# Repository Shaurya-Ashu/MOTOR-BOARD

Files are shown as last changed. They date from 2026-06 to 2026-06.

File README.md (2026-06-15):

# MOTOR-BOARD
It's a DEV Board specially developed for controlling motors.
We can use this dev board to make anything from a moving car a self balancing robot or even a CNC mill machine.
It's like a all in one mobility powerhouse.

# Why 
 becaue i always wamted one 
 a dev borad which i can directly use to drive a car or make a robotic arm possibilities are endless.
 And also creating a dev board is a fun project.

# BOM
 We have a normal [BOM](BOM/Untitled%20spreadsheet%20-%20BOM.csv)
 & a interactive one https://shaurya-ashu.github.io/MOTOR-BOARD/index.html

# Zine
 Frame 1-2

 It's my first time creating this
 
# Info
It is a dev board based on ESP32-S3-WROOM-1 (My FAV.) mcu, specially designed for multiple types of motors from brushed DC motors, Servo Motors stepper motors etc.
Screenshot 2026-06-09 at 7 26 10 PM

I have used a USB-C port for programming and powering Electronics and the dedicated 3S input for powering the motors.
Screenshot 2026-06-09 at 7 27 20 PM

I have used a INPUT VOLTAGE MULTIPLEXER for selecting between the USB-C power source and battery power source to power the electronics , its is set default to USB power and if USB power is unavailable, then it uses the battery power source.
I get to know about this in a Instagram reel where someone was building custom ESC.
Screenshot 2026-06-09 at 7 28 06 PM

We have to dedicated LDO to convert USB power source and battery power source to 3.3v .
It's a AMS1117-3.3 rated output at 3.3v @1000mah 
Screenshot 2026-06-09 at 7 28 37 PM

It has three peripheral interfaces which you are UART,I2C & SPI .
Which we can use to connect different sensors displays and other devices and also setup a serial communication between two MCU.

Screenshot 2026-06-09 at 7 29 10 PM

Now lets begin with the main part of the schematics the motor drivers and the selector .
So i have used two 3-Way Switches for selecting between diff motors to drive .
we have 2x-TB6612FNG to drive 4x-DC brushless motor
Screenshot 2026-06-09 at 7 29 52 PM

4x-Breakout_A4988 where we can insert A4988 Module to run 4x-Stepper motors.
Screenshot 2026-06-09 at 7 30 38 PM

also to power the servo i have used 2x-ST1S41PHR buck converter so that each servo can get up-to 6v @1A .
Screenshot 2026-06-09 at 7 31 12 PM

Now the the switching part so i have divide it like this in the diagram below :-
DIAGRAM-SELECTOR
Here the vcc enables the drivers for dc-motors & stepper motor and the buck converter for servo's.
The control pins are connected to same pins for for dc-motors , stepper motor & servo .

# Config

 So, all the three thing the dc motor driver , servo & stepper are connected to same GPIO's 
 like this 
 | Net | ESP32-S3 GPIO | Servo Output | A4988 Stepper Driver | TB6612FNG DC Driver |
|:---:|:-------------:|:-------------:|:--------------------:|:-------------------:|
| A1  | GPIO1  | Servo A1 | Stepper 1 ENABLE | M1 PWMA |
| A2  | GPIO2  | Servo A2 | Stepper 1 STEP   | M2 PWMB |
| A3  | GPIO15 | Servo A3 | Stepper 1 DIR    | M1 AIN1 |
| A4  | GPIO4  | Servo A4 | Stepper 2 ENABLE | M1 AIN2 |
| A5  | GPIO5  | Servo A5 | Stepper 2 STEP   | M2 BIN1 |
| A6  | GPIO6  | Servo A6 | Stepper 2 DIR    | M2 BIN2 |
| A7  | GPIO7  | Servo A7 | Stepper 3 ENABLE | M3 PWMA |
| A8  | GPIO22 | Servo A8 | Stepper 3 STEP   | M4 PWMB |
| A9  | GPIO8  | — | Stepper 3 DIR    | M3 AIN1 |
| A10 | GPIO9  | — | Stepper 4 ENABLE | M3 AIN2 |
| A11 | GPIO10 | — | Stepper 4 STEP   | M4 BIN1 |
| A12 | GPIO11 | — | Stepper 4 DIR    | M4 BIN2 |

# PCB

So it's a 4 layer PCB
Confi as:
# Top layer - Signal
Screenshot 2026-06-10 at 1 47 24 PM

# 1 inner layer - GND
Screenshot 2026-06-10 at 1 47 37 PM

# 2 inner layer - Power
Screenshot 2026-06-10 at 1 47 53 PM

# Bottom layer - Signal
Screenshot 2026-06-10 at 1 48 08 PM

the GND layer is divide into two parts then normal electronics and the power/driver electronics and is connected by a single trace .
Screenshot 2026-06-10 at 1 47 37 PM

# Img 

motor-board-img
Screenshot 2026-06-10 at 11 27 02 AM
Screenshot 2026-06-10 at 12 37 49 PM

# Build

Just Order the production gerber file from any pcb manufacturer
And other all the components of DigiKey as listed in the bom

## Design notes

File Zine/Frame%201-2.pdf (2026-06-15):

# MOTOR BOARD

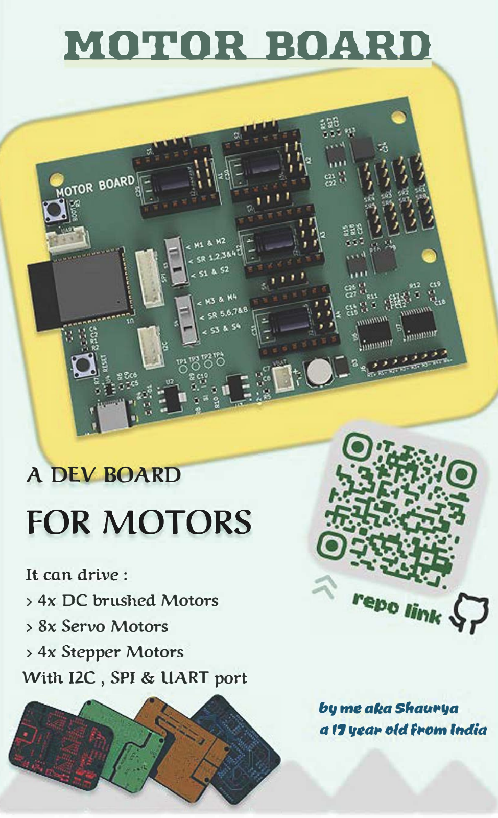
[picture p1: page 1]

A DEV BOARD

## FOR MOTORS

It can drive :
> 4x DC brushed Motors
> 8x Servo Motors
> 4x Stepper Motors
With 12C , SPI & UART port

b!f me alta S"ac.,.11a
a 1711ea,. o(d ftoom India

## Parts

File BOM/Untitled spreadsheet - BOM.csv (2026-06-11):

BILL OF MATERIALS
Item No. | Reference(s) | Description | Footprint / Package | Qty | Unit Price (USD) | Total Value (USD) | Purchase Link
1 | A1, A2, A3, A4 | Pololu A4988 Stepper Motor Driver Breakout (Black Ed.) | Module 15.2×20.3 mm (16-pin) | 4 | $5.95 | $23.80 | https://www.pololu.com/product/2128
2 | C1, C5, C6, C7, C8 | Capacitor, 22 µF, SMD 0603 | C_0603_1608Metric HandSolder | 5 | $0.12 | $0.60 | https://www.digikey.com/en/products/filter/ceramic-capacitors/60
3 | C2, C9, C10, C11, C23, C25 | Capacitor, 1 µF, SMD 0603 | C_0603_1608Metric HandSolder | 6 | $0.10 | $0.60 | https://www.digikey.com/en/products/filter/ceramic-capacitors/60
4 | C3, C4, C12, C14, C17, C18 | Capacitor, 100 nF (0.1 µF), SMD 0603 | C_0603_1608Metric HandSolder | 6 | $0.08 | $0.48 | https://www.digikey.com/en/products/filter/ceramic-capacitors/60
5 | C13, C15, C16, C19, C21, C22, C26, C27 | Capacitor, 10 µF, SMD 0603 | C_0603_1608Metric HandSolder | 8 | $0.15 | $1.20 | https://www.digikey.com/en/products/filter/ceramic-capacitors/60
6 | C20 | Capacitor, 10 µF, Electrolytic THT | C_Elec 6.3×5.4 mm | 1 | $0.20 | $0.20 | https://www.digikey.com/en/products/filter/aluminum-electrolytic-capacitors/58
7 | C24, C28 | Capacitor, 47 µF, SMD 0603 | C_0603_1608Metric HandSolder | 2 | $0.22 | $0.44 | https://www.digikey.com/en/products/filter/ceramic-capacitors/60
8 | C29, C30, C31, C32 | Capacitor, 100 µF, Electrolytic THT | C_Rect L7.2×W3.5 mm P5.00 mm | 4 | $0.25 | $1.00 | https://www.digikey.com/en/products/filter/aluminum-electrolytic-capacitors/58
9 | D1, D2 | LED, General Purpose, SMD 0201 (0603 pads) | LED_0201_0603Metric HandSolder | 2 | $0.10 | $0.20 | https://www.digikey.com/en/products/filter/leds-through-hole/93
10 | D3 | SMBJ30CA-13-F — 30 V Bidirectional TVS Diode | SMB (DO-214AA) / DIOM4336 | 1 | $0.55 | $0.55 | https://www.digikey.com/en/products/detail/diodes-incorporated/SMBJ30CA-13-F/814937
11 | IC1, IC2 | ST1S41PHR — 3 A Step-Down Switching Regulator | SOIC-9 (SOIC127P600X170-9N) | 2 | $1.85 | $3.70 | https://www.mouser.com/ProductDetail/STMicroelectronics/ST1S41PHR?qs=GlLcxsc1hfH42vbX3xy6fg%3D%3D
12 | J1 | 2340901-1 — TE Connectivity Connector | TE_2340901-1 | 1 | $1.20 | $1.20 | https://www.digikey.com/en/products/detail/te-connectivity-amp-connectors/2340901-1/
13 | J2 | JST PH 2-Pin Vertical Connector (2.00 mm pitch) | JST_PH B2B-PH-K 1×02 P2.00 mm | 1 | $0.35 | $0.35 | https://www.digikey.com/en/products/detail/jst-sales-america-inc/B2B-PH-K-S-LF-SN/926626
14 | J3, J5 | JST PH 4-Pin Vertical Connector (2.00 mm pitch) | JST_PH B4B-PH-K 1×04 P2.00 mm | 2 | $0.45 | $0.90 | https://www.digikey.com/en/products/detail/jst-sales-america-inc/B4B-PH-K-S-LF-SN/926628
15 | J4 | JST PH 6-Pin Vertical Connector (2.00 mm pitch) | JST_PH B6B-PH-K 1×06 P2.00 mm | 1 | $0.55 | $0.55 | https://www.digikey.com/en/products/detail/jst-sales-america-inc/B6B-PH-K-S-LF-SN/926630
16 | J6 | 1×8 Female Pin Header 2.54 mm pitch | PinHeader_1×08 P2.54 mm Vertical | 1 | $0.30 | $0.30 | https://www.digikey.com/en/products/filter/rectangular-connectors-headers-receptacles/315
17 | J7–J14 (8 pcs) | 1×3 Male Pin Header 2.54 mm pitch | PinHeader_1×03 P2.54 mm Vertical | 8 | $0.10 | $0.80 | https://www.digikey.com/en/products/filter/rectangular-connectors-headers-male-pins/314
18 | J15, J16, J17, J18 | 1×4 Male Pin Header 2.54 mm pitch | PinHeader_1×04 P2.54 mm Vertical | 4 | $0.12 | $0.48 | https://www.digikey.com/en/products/filter/rectangular-connectors-headers-male-pins/314
19 | J19–J30 (12 pcs) | 1×2 Male Pin Header 2.54 mm pitch | PinHeader_1×02 P2.54 mm Vertical | 12 | $0.08 | $0.96 | https://www.digikey.com/en/products/filter/rectangular-connectors-headers-male-pins/314
20 | L1, L2 | XAL5030-332MEC — 3.3 µH 4.7 A Shielded Power Inductor | XAL5030 (5×5×3 mm) | 2 | $1.98 | $3.96 | https://www.mouser.com/ProductDetail/Coilcraft/XAL5030-332MEC?qs=zCSbvcPd3pYGD73YPsvPxA%3D%3D
21 | R1, R13, R16 | Resistor, 10 kΩ, SMD 0603 | R_0603_1608Metric HandSolder | 3 | $0.05 | $0.15 | https://www.digikey.com/en/products/filter/chip-resistor-surface-mount/52
22 | R2, R3 | Resistor, 0 Ω (Jumper), SMD 0603 | R_0603_1608Metric HandSolder | 2 | $0.05 | $0.10 | https://www.digikey.com/en/products/filter/chip-resistor-surface-mount/52
23 | R4, R5, R10, R11, R12, R17, R18 | Resistor, 1 kΩ, SMD 0603 | R_0603_1608Metric HandSolder | 7 | $0.05 | $0.35 | https://www.digikey.com/en/products/filter/chip-resistor-surface-mount/52
24 | R6, R7 | Resistor, 5.1 kΩ, SMD 0603 | R_0603_1608Metric HandSolder | 2 | $0.05 | $0.10 | https://www.digikey.com/en/products/filter/chip-resistor-surface-mount/52
25 | R8, R9 | Resistor, 47 Ω, SMD 0603 | R_0603_1608Metric HandSolder | 2 | $0.05 | $0.10 | https://www.digikey.com/en/products/filter/chip-resistor-surface-mount/52
26 | R14, R15 | Resistor, 68 kΩ, SMD 0603 | R_0603_1608Metric HandSolder | 2 | $0.05 | $0.10 | https://www.digikey.com/en/products/filter/chip-resistor-surface-mount/52
27 | S1, S2 | Tactile Push Button (BUTT-2) | SW_BUTT-2 | 2 | $0.25 | $0.50 | https://www.digikey.com/en/products/filter/tactile-switches/197
28 | S3, S4 | OS103011MS8QP1 — SPDT Slide Switch | OS103011MS8QP1 | 2 | $0.45 | $0.90 | https://www.digikey.com/en/products/detail/c-k/OS103011MS8QP1/1981429
29 | TP1 | Test Point — VBUS 3.3 V | TestPoint_Pad D1.5 mm | 1 | $0.05 | $0.05 | https://www.digikey.com/en/products/filter/test-points/639
30 | TP2 | Test Point — VBAT 3.3 V | TestPoint_Pad D1.5 mm | 1 | $0.05 | $0.05 | https://www.digikey.com/en/products/filter/test-points/639
31 | TP3, TP4 | Test Point — General Purpose | TestPoint_Pad D1.5 mm | 2 | $0.05 | $0.10 | https://www.digikey.com/en/products/filter/test-points/639
32 | U1 | ESP32-S3-WROOM-1 — WiFi/BT5 Module (PCB ant.) | RF_Module:ESP32-S3-WROOM-1 | 1 | $3.50 | $3.50 | https://www.digikey.com/en/products/detail/espressif-systems/ESP32-S3-WROOM-1-N4/16162639
33 | U2, U3 | AMS1117-3.3 — 1 A LDO Voltage Regulator 3.3 V | SOT-223-3 TabPin2 | 2 | $0.30 | $0.60 | https://www.digikey.com/en/products/detail/umw/AMS1117-3.3/17084460
34 | U4 | USBLC6-2SC6 — USB ESD Protection, SOT-23-6 | SOT-23-6 | 1 | $0.54 | $0.54 | https://www.digikey.com/en/products/detail/stmicroelectronics/USBLC6-2SC6/1787534
35 | U5 | TPS2116DRLR — Power Mux / Priority Switch | SOT-FL50P160×60-8N (VSON-8) | 1 | $0.80 | $0.80 | https://www.digikey.com/en/products/detail/texas-instruments/TPS2116DRLR/15205127
36 | U6, U7 | TB6612FNG — Dual H-Bridge DC Motor Driver | SSOP-24 5.3×8.2 mm P0.65 mm | 2 | $2.72 | $5.44 | https://www.digikey.com/en/products/detail/toshiba-semiconductor-and-storage/TB6612FNGC8EL/1730134
37 | PCB | PCB | -- | 5 | $1.40 | $7.00 | NA
GRAND TOTAL (USD) |  |  |  |  |  | $62.65

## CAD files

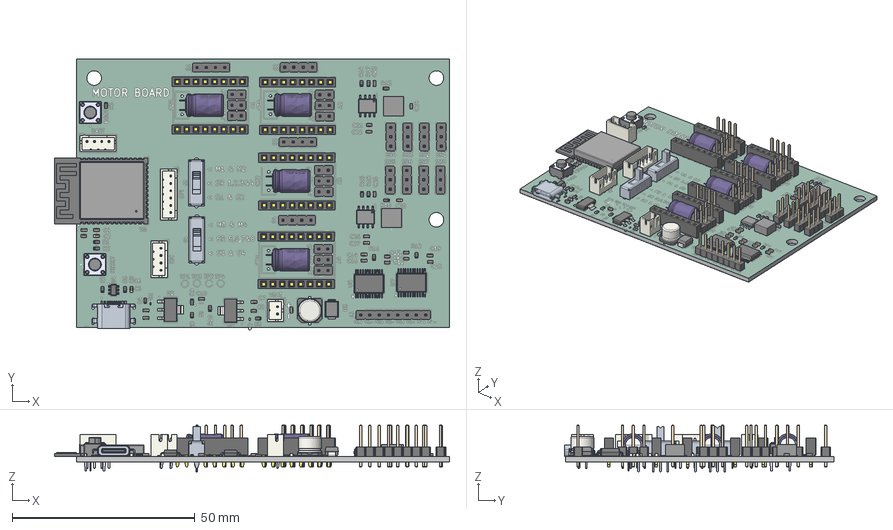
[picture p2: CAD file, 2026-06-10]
PCB/3D Model/moto board.step
107.9 x 74.1 x 12.8 mm
Pins x 2
8er Pin Header Female x 8
R_0603_1608Metric x 18
C_0603_1608Metric x 27
PinHeader_1x02_P2.54mm_Vertical x 12
BUTT-2 x 2
PinHeader_1x03_P2.54mm_Vertical x 8
User Library-Cap-EL(12_5x20-5)T x 4
ESP32-S3-WROOM-1
OS103011MS8QP1 x 2
PinsArrayLR x 2
ThermalPad x 2
SOT-223 x 2
JST_PH_B4B-PH-K_1x04_P2.00mm_Vertical x 2
PinHeader_1x04_P2.54mm_Vertical x 4
SOT-23-6
PinHeader_1x08_P2.54mm_Vertical
JST_PH_B6B-PH-K_1x06_P2.00mm_Vertical
C_Elec_6.3x5.4
LED_0201_0603Metric x 2
SSOP-24_5.3x8.2mm_P0.65mm x 2
JST_PH_B2B-PH-K_1x02_P2.00mm_Vertical
SMBJ30CA-13-F
moto board_silkscreen x 2
moto board_soldermask x 2
moto board_PCB

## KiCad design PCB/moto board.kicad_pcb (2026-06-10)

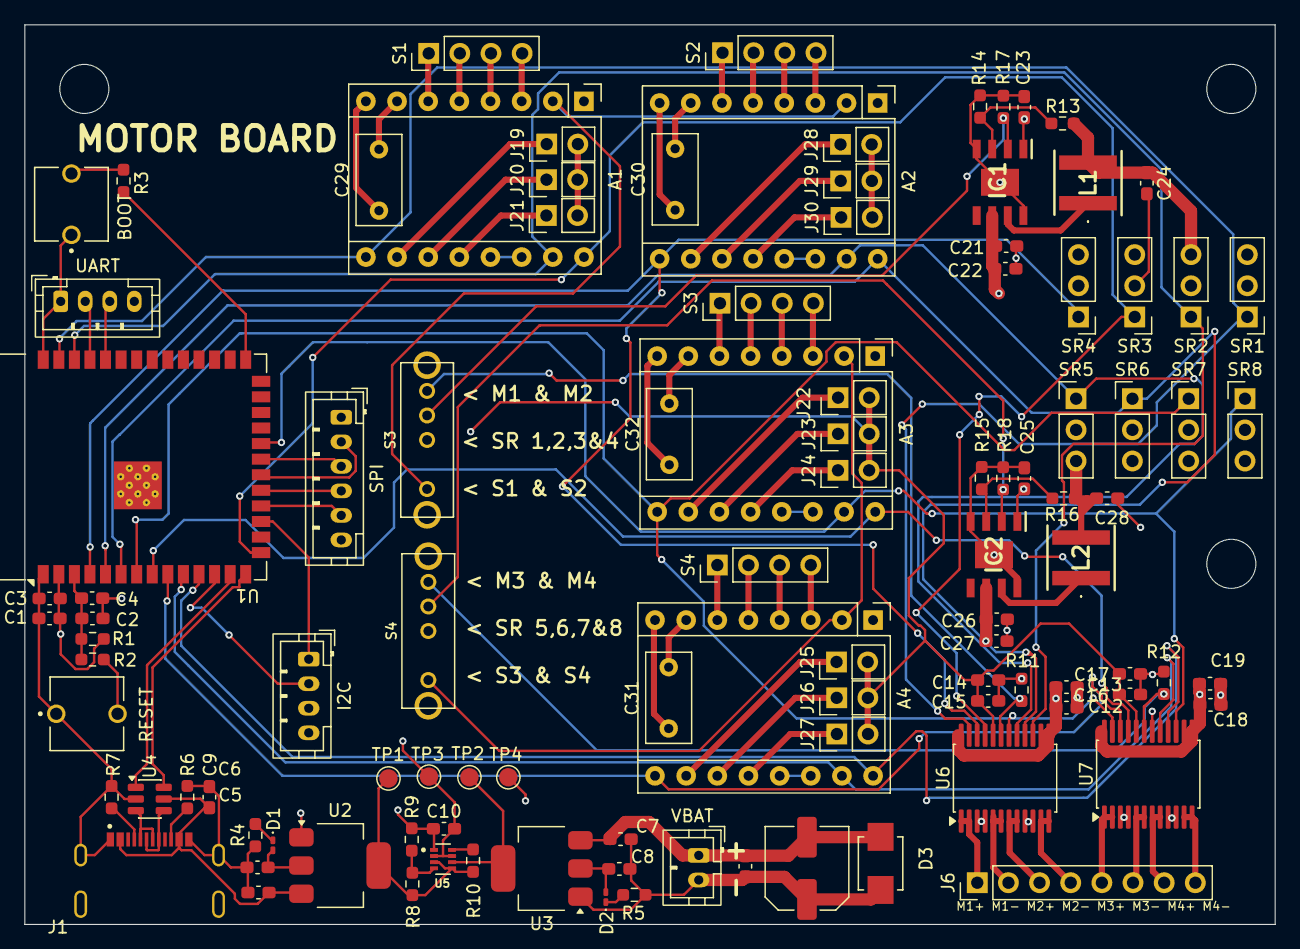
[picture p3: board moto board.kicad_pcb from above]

Board: 4 copper layers, 102.0 x 73.4 mm, 106 parts (0 on the bottom side), 92 nets.

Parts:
A1, A2, A3, A4: Pololu_Breakout_A4988; Pololu_Breakout-16_15.2x20.3mm
BOOT: BUTT-2; SW_BUTT-2
C1, C5, C6, C7, C8: 22uf; C_0603_1608Metric_Pad1.08x0.95mm_HandSolder
C2, C9, C10, C11, C23, C25: 1uf; C_0603_1608Metric_Pad1.08x0.95mm_HandSolder
C3, C4, C12, C14, C17, C18: 0.1uf; C_0603_1608Metric_Pad1.08x0.95mm_HandSolder
C13, C15, C16, C19, C21, C22, C26, C27: 10uf; C_0603_1608Metric_Pad1.08x0.95mm_HandSolder
C20: 10UF; C_Elec_6.3x5.4
C24, C28: 47uf; C_0603_1608Metric_Pad1.08x0.95mm_HandSolder
C29, C30, C31, C32: 100uf; C_Rect_L7.2mm_W3.5mm_P5.00mm
D1, D2: LED; LED_0201_0603Metric_Pad0.64x0.40mm_HandSolder
D3: SMBJ30CA-13-F; DIOM4336X265N
I2C: Conn_01x04_Pin; JST_PH_B4B-PH-K_1x04_P2.00mm_Vertical
IC1, IC2: ST1S41PHR; SOIC127P600X170-9N
J1: 2340901-1; TE_2340901-1
J6: Conn_01x08_Socket; PinHeader_1x08_P2.54mm_Vertical
J19, J20, J21, J22, J23, J24, J25, J26, J27, J28, J29, J30: Conn_01x02_Pin; PinHeader_1x02_P2.54mm_Vertical
L1, L2: XAL5030-332MEC; XAL5030332MEC
R1, R13, R16: 10k; R_0603_1608Metric_Pad0.98x0.95mm_HandSolder
R2, R3: 0; R_0603_1608Metric_Pad0.98x0.95mm_HandSolder
R4, R5, R10, R11, R12, R17, R18: 1K; R_0603_1608Metric_Pad0.98x0.95mm_HandSolder
R6, R7: 5K1; R_0603_1608Metric_Pad0.98x0.95mm_HandSolder
R8, R9: 47; R_0603_1608Metric_Pad0.98x0.95mm_HandSolder
R14, R15: 68k; R_0603_1608Metric_Pad0.98x0.95mm_HandSolder
RESET: BUTT-2; SW_BUTT-2
S1, S2, S3#2, S4#2: Conn_01x04_Pin; PinHeader_1x04_P2.54mm_Vertical
S3, S4: OS103011MS8QP1; OS102011MS8QP1
SPI: Conn_01x06_Pin; JST_PH_B6B-PH-K_1x06_P2.00mm_Vertical
SR1, SR2, SR3, SR4, SR5, SR6, SR7, SR8: Conn_01x03_Pin; PinHeader_1x03_P2.54mm_Vertical
TP1: VBUS_3.3V; TestPoint_Pad_D1.5mm
TP2: VBAT_3.3V; TestPoint_Pad_D1.5mm
TP3, TP4: TestPoint; TestPoint_Pad_D1.5mm
U1: ESP32-S3-WROOM-1
U2, U3: AMS1117-3.3; SOT-223-3_TabPin2
U4: USBLC6-2SC6; SOT-23-6
U5: TPS2116DRLR; SOTFL50P160X60-8N
U6, U7: TB6612FNG; SSOP-24_5.3x8.2mm_P0.65mm
UART: Conn_01x04_Pin; JST_PH_B4B-PH-K_1x04_P2.00mm_Vertical
VBAT: Conn_01x02_Pin; JST_PH_B2B-PH-K_1x02_P2.00mm_Vertical

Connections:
/6V_1: C24.1, L1.2, R13.1, SR1.3, SR2.3, SR3.3, SR4.3
/6V_2: C28.1, L2.2, R16.1, SR5.3, SR6.3, SR7.3, SR8.3
/A1: A1.9 (~ENABLE), SR1.1, U1.39 (IO1), U6.23 (PWMA)
/A2: A1.15 (STEP), SR2.1, U1.38 (IO2), U6.15 (PWMB)
/A3: A1.16 (DIR), SR3.1, U1.15 (IO3), U6.21 (AIN1)
/A4: A2.9 (~ENABLE), SR4.1, U1.4 (IO4), U6.22 (AIN2)
/A5: A2.15 (STEP), SR5.1, U1.5 (IO5), U6.17 (BIN1)
/A6: A2.16 (DIR), SR6.1, U1.6 (IO6), U6.16 (BIN2)
/A7: A3.9 (~ENABLE), SR7.1, U1.7 (IO7), U7.23 (PWMA)
/A8: A3.15 (STEP), SR8.1, U1.22 (IO14), U7.15 (PWMB)
/A9: A3.16 (DIR), U1.8 (IO15), U7.21 (AIN1)
/A10: A4.9 (~ENABLE), U1.9 (IO16), U7.22 (AIN2)
/A11: A4.15 (STEP), U1.10 (IO17), U7.17 (BIN1)
/A12: A4.16 (DIR), U1.11 (IO18), U7.16 (BIN2)
/BOOT: R3.1, U1.27 (IO0)
/CS: SPI.5, U1.18 (IO10)
/EN: C2.2, C4.2, R1.1, R2.1, U1.3 (EN)
/EN1: IC1.2 (EN), R17.1, S3.3
/EN2: IC2.2 (EN), R18.1, S4.3
/M1: J6.1, U6.1 (AO1), U6.2 (AO1)
/M2: J6.2, U6.5 (AO2), U6.6 (AO2)
/M3: J6.3, U6.7 (BO2), U6.8 (BO2)
/M4: J6.4, U6.11 (BO1), U6.12 (BO1)
/M5: J6.5, U7.1 (AO1), U7.2 (AO1)
/M6: J6.6, U7.5 (AO2), U7.6 (AO2)
/M7: J6.7, U7.7 (BO2), U7.8 (BO2)
/M8: J6.8, U7.11 (BO1), U7.12 (BO1)
/MISO: SPI.3, U1.21 (IO13)
/MOSI: SPI.4, U1.19 (IO11)
/N: U1.13 (USB_D-), U4.1 (I/O1)
/P: U1.14 (USB_D+), U4.6 (I/O1)
/RX: U1.36 (RXD0), UART.3
/SCL: I2C.2, U1.12 (IO8)
/SCLK: SPI.2, U1.20 (IO12)
/SDA: I2C.1, U1.17 (IO9)
/STBY1: R11.1, S3.4, U6.19 (STBY)
/STBY2: R12.1, S4.4, U7.19 (STBY)
/TX: U1.37 (TXD0), UART.2
/USB_DN: J1.A7 (DN1), J1.B7 (DN2), U4.3 (I/O2)
/USB_DP: J1.A6 (DP1), J1.B6 (DP2), U4.4 (I/O2)
/VBAT: A1.8 (VMOT), A2.8 (VMOT), A3.8 (VMOT), A4.8 (VMOT), C7.2, C11.2, C12.2, C13.2, C18.2, C19.2, C20.2, C21.1, C22.1, C23.1, C25.1, C26.1, C27.1, C29.1, C30.1, C31.1, C32.1, D3.1, IC1.1 (VINA), IC1.6 (VINSW), IC2.1 (VINA), IC2.6 (VINSW), U3.3 (VI), U6.13 (VM2), U6.14 (VM3), U6.24 (VM1), U7.13 (VM2), U7.14 (VM3), U7.24 (VM1), VBAT.1
/VBAT_3.3: C8.1, D2.2 (A), TP2.1, U3.2 (VO), U5.6 (VIN2)
/VBUS: C5.2, C9.2, J1.A4/B9 (VBUS_A), J1.B4/AP (VBUS_B), U2.3 (VI), U4.5 (VBUS)
/VBUS_3.3: C6.1, D1.2 (A), R8.2, R10.2, TP1.1, U2.2 (VO), U5.3 (VIN1), U5.5 (MODE)
/vdd_s1: A1.2 (VDD), A2.2 (VDD), S3.1
/vdd_s2: A3.2 (VDD), A4.2 (VDD), S4.1
GND: A1.1 (GND), A1.7 (GND), A2.1 (GND), A2.7 (GND), A3.1 (GND), A3.7 (GND), A4.1 (GND), A4.7 (GND), BOOT.1, C1.1, C2.1, C3.1, C4.1, C5.1, C6.2, C7.1, C8.2, C9.1, C10.1, C11.1, C12.1, C13.1, C14.1, C15.1, C16.1, C17.1, C18.1, C19.1, C20.1, C21.2, C22.2, C23.2, C24.2, C25.2, C26.2, C27.2, C28.2, C29.2, C30.2, C31.2, C32.2, D3.2, I2C.3, IC1.4 (GND), IC1.8 (PGND), IC1.9 (EPAD), IC2.4 (GND), IC2.8 (PGND), IC2.9 (EPAD), J1.A1/B12 (GND_A), J1.B1/A12 (GND_B), J1.SH1 (SHIELD), J1.SH2 (SHIELD), J1.SH3 (SHIELD), J1.SH4 (SHIELD), R4.2, R5.2, R6.2, R7.1, R9.2, R11.2, R12.2, R14.2, R15.2, R17.2, R18.2, RESET.1, SPI.6, SR1.2, SR2.2, SR3.2, SR4.2, SR5.2, SR6.2, SR7.2, SR8.2, TP4.1, U1.1 (GND), U1.40 (GND), U1.41 (GND), U2.1 (GND), U3.1 (GND), U4.2 (GND), U5.1 (GND), U6.3 (PGND1), U6.4 (PGND1), U6.9 (PGND2), U6.10 (PGND2), U6.18 (GND), U7.3 (PGND1), U7.4 (PGND1), U7.9 (PGND2), U7.10 (PGND2), U7.18 (GND), UART.1, VBAT.2
unnamed: A1.4 (1A), S1.3
unnamed: A1.3 (1B), S1.4
unnamed: A1.5 (2A), S1.2
unnamed: A1.6 (2B), S1.1
unnamed: A1.10 (MS1), J19.1
unnamed: A1.11 (MS2), J20.1
unnamed: A1.12 (MS3), J21.1
unnamed: A1.13 (~RESET), A1.14 (~SLEEP)
unnamed: A2.4 (1A), S2.3
unnamed: A2.3 (1B), S2.4
unnamed: A2.5 (2A), S2.2
unnamed: A2.6 (2B), S2.1
unnamed: A2.10 (MS1), J28.1
unnamed: A2.11 (MS2), J29.1
unnamed: A2.12 (MS3), J30.1
unnamed: A2.13 (~RESET), A2.14 (~SLEEP)
unnamed: A3.4 (1A), S3#2.3
unnamed: A3.3 (1B), S3#2.4
unnamed: A3.5 (2A), S3#2.2
unnamed: A3.6 (2B), S3#2.1
unnamed: A3.10 (MS1), J22.1
unnamed: A3.11 (MS2), J23.1
unnamed: A3.12 (MS3), J24.1
unnamed: A3.13 (~RESET), A3.14 (~SLEEP)
unnamed: A4.4 (1A), S4#2.3
unnamed: A4.3 (1B), S4#2.4
unnamed: A4.5 (2A), S4#2.2
unnamed: A4.6 (2B), S4#2.1
unnamed: A4.10 (MS1), J25.1
unnamed: A4.11 (MS2), J26.1
unnamed: A4.12 (MS3), J27.1
unnamed: A4.13 (~RESET), A4.14 (~SLEEP)
unnamed: D1.1 (K), R4.1
unnamed: D2.1 (K), R5.1
unnamed: IC1.3 (FB), R13.2, R14.1
unnamed: IC1.7 (SW), L1.1
unnamed: IC2.3 (FB), R15.1, R16.2
unnamed: IC2.7 (SW), L2.1
unnamed: J1.A5 (CC1), R7.2
unnamed: J1.B5 (CC2), R6.1
unnamed: R2.2, RESET.2
unnamed: BOOT.2, R3.2
unnamed: R8.1, R9.1, U5.4 (PR1)
unnamed: R10.1, U5.8 (ST)
VCC: C1.2, C3.2, C10.2, C14.2, C15.2, C16.2, C17.2, I2C.4, J19.2, J20.2, J21.2, J22.2, J23.2, J24.2, J25.2, J26.2, J27.2, J28.2, J29.2, J30.2, R1.2, S3.2, S4.2, SPI.1, TP3.1, U1.2 (3V3), U5.2 (VOUT), U5.7 (VOUT), U6.20 (VCC), U7.20 (VCC), UART.4

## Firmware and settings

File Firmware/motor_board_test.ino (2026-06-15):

/*
 * MOTOR-BOARD Simple Test Sketch
 * Target: ESP32-S3-WROOM-1
 *
 * Tests the shared control pins (A1-A12) that are wired in parallel to:
 *   - 2x TB6612FNG (DC motor drivers)
 *   - 4x A4988 stepper driver footprints
 *   - 8x Servo outputs (A1-A8)
 *
 * Since A1-A12 are shared between drivers via the 3-way selector switches,
 * make sure the switches are set to the matching mode (DC / Stepper / Servo)
 * before running the corresponding test, and that the driver/servo rail
 * (VCC / battery input) is powered.
 *
 * Open Serial Monitor at 115200 baud, then send:
 *   1 -> GPIO toggle test (A1-A12)   - generic continuity/output check
 *   2 -> Servo sweep test (A1-A8)    - needs ESP32Servo library
 *   3 -> Stepper test (Stepper 1: A1=ENABLE, A2=STEP, A3=DIR)
 *   4 -> DC motor test (M1: A1=PWMA, A3=AIN1, A4=AIN2)
 */

#include <Arduino.h>
#include <ESP32Servo.h>


const int pinA[12]      = {1, 2, 15, 4, 5, 6, 7, 22, 8, 9, 10, 11};
const char* pinName[12] = {"A1","A2","A3","A4","A5","A6","A7","A8","A9","A10","A11","A12"};

void allLow() {
  for (int i = 0; i < 12; i++) {
    digitalWrite(pinA[i], LOW);
  }
}

void printMenu() {
  Serial.println();
  Serial.println("MOTOR-BOARD Test Sketch");
  Serial.println("1: GPIO toggle test (A1-A12)");
  Serial.println("2: Servo sweep test (A1-A8)");
  Serial.println("3: Stepper test (Stepper 1: A1=EN, A2=STEP, A3=DIR)");
  Serial.println("4: DC motor test (M1: A1=PWMA, A3=AIN1, A4=AIN2)");
  Serial.println("Send a number to run a test:");
}

void setup() {
  Serial.begin(115200);
  delay(1000);

  for (int i = 0; i < 12; i++) {
    pinMode(pinA[i], OUTPUT);
    digitalWrite(pinA[i], LOW);
  }

  printMenu();
}
void gpioToggleTest() {
  Serial.println("Running GPIO toggle test...");
  for (int i = 0; i < 12; i++) {
    Serial.printf("Toggling %s (GPIO%d)\n", pinName[i], pinA[i]);
    digitalWrite(pinA[i], HIGH);
    delay(300);
    digitalWrite(pinA[i], LOW);
    delay(200);
  }
  Serial.println("Done.");
}
void servoSweepTest() {
  Servo servos[8];
  Serial.println("Running servo sweep test on A1-A8...");

  for (int i = 0; i < 8; i++) {
    servos[i].setPeriodHertz(50);
    servos[i].attach(pinA[i], 500, 2400);
  }

  for (int pos = 0; pos <= 180; pos += 10) {
    for (int i = 0; i < 8; i++) servos[i].write(pos);
    delay(100);
  }
  for (int pos = 180; pos >= 0; pos -= 10) {
    for (int i = 0; i < 8; i++) servos[i].write(pos);
    delay(100);
  }

  for (int i = 0; i < 8; i++) servos[i].detach();
  Serial.println("Done.");
}
void stepperTest() {
  Serial.println("Running stepper test (Stepper 1)...");

 
  digitalWrite(pinA[0], LOW);  
  digitalWrite(pinA[2], HIGH); 

  for (int i = 0; i < 200; i++) {  
    digitalWrite(pinA[1], HIGH);
    delayMicroseconds(800);
    digitalWrite(pinA[1], LOW);
    delayMicroseconds(800);
  }

  digitalWrite(pinA[0], HIGH); 
  Serial.println("Done.");
}

void dcMotorTest() {
  Serial.println("Running DC motor test (M1)...");

  digitalWrite(pinA[2], HIGH);
  digitalWrite(pinA[3], LOW);  

  for (int duty = 0; duty <= 255; duty += 5) {
    analogWrite(pinA[0], duty);
    delay(50);
  }
  for (int duty = 255; duty >= 0; duty -= 5) {
    analogWrite(pinA[0], duty);
    delay(50);
  }

  digitalWrite(pinA[2], LOW);
  digitalWrite(pinA[3], LOW);
  Serial.println("Done.");
}
void loop() {
  if (Serial.available()) {
    char c = Serial.read();
    allLow();

    switch (c) {
      case '1': gpioToggleTest(); break;
      case '2': servoSweepTest(); break;
      case '3': stepperTest();    break;
      case '4': dcMotorTest();    break;
      default: break; 
    }

    printMenu();
  }
}

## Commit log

2026-06-11 Rename PCB/moto board_101.95x73.35mm_for_Default.zip to Production_Gerber.zip
2026-06-12 Rename moto board_101.95x73.35mm_for_Default.zip to moto board_Gerber.zip
